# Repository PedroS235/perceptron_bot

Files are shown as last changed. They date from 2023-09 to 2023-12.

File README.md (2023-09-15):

# Perceptron Bot: Your Path to Autonomous Robotics

**Welcome to the Perceptron Bot Repository!**

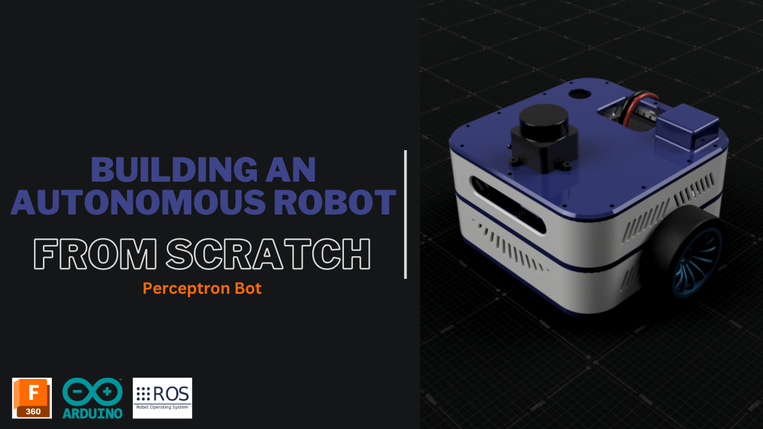
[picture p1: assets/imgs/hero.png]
Perceptron Bot


## Table of contents

<!--toc:start-->

- [Table of contents](#table-of-contents)
- [Introduction](#introduction)
- [Getting Started](#getting-started)
  - [Dependencies](#dependencies)
- [Vision and Purpose](#vision-and-purpose)
- [Repository Highlights](#repository-highlights)
- [YouTube Series](#youtube-series)
- [Join the Adventure](#join-the-adventure)
- [Documentation](#documentation)
- [License](#license)
- [Contact](#contact)
  <!--toc:end-->

## Introduction

Welcome to the captivating world of the Perceptron Bot!
This project embarks on an exhilarating journey, chronicled through an
immersive YouTube series, guiding you through the creation of an autonomous
robot right from its foundational components. The Perceptron Bot, at its core,
serves as the dynamic canvas for this venture, offering a versatile platform
to assemble a range of integral elements, including LiDAR, onboard computing,
and a diverse array of sensors.

## Getting Started

To begin with, you will need to clone this repo. Since it contains submodules,
you will need to clone using the following command:

```sh
git clone --recurse-submodules git@github.com:PedroS235/perceptron_bot.git
```

### Dependencies

- Ubuntu 22.04
- PlatformIO (CLI)
- ROS Humble and above

## Vision and Purpose

The Perceptron Bot isn't just a robot – it's a realization of a vision.
Its purpose is to empower robotic enthusiasts, both beginners and experts alike,
with the tools and knowledge to construct a differential robot capable of autonomous operation.
Designed to be a living example of adaptability, this robotic platform paves
the way for seamless integration of future enhancements and additional sensors.
Its architecture is meticulously crafted to ensure effortless integration,
facilitating the continuous evolution of your robotic creation.

## Repository Highlights

Within this repository, you'll find the core of the Perceptron Bot project:

- **Low-Level Drivers:** Essential low-level drivers are the backbone of the robot's functionality.
- **Setup Scripts:** Curated scripts expedite setup and streamline the integration of the Perceptron Workspace [`perceptron_ws`](https://github.com/PedroS235/perceptron_ws) – a ROS-driven workspace housing critical packages.
- **Documentation:** A set of guidelines and documentation to follow along.

## YouTube Series

The captivating YouTube series offers a holistic learning experience:

- **Design in 3D:** Craft an elegant chassis design through 3D modeling, merging aesthetics and functionality.
- **Delve into Low-Level Development:** Explore motor drivers and serial protocols, unraveling the mysteries of low-level robotics.
- **Simulation with Gazebo:** Immerse yourself in virtual simulation using Gazebo, refining your bot's behavior in diverse scenarios.
- **Master ROS2 and Navigation:** Elevate your coding skills with ROS2, culminating in the integration of the Navigation2 stack for autonomous navigation.

## Join the Adventure

Enthusiasts and developers are invited to contribute to the Perceptron Bot project:

1. **Fork this Repository:** Create a personal development space.
2. **Branch Out:** Develop your contributions in dedicated branches.
3. **Ignite Change:** Tackle issues, enhance features, and propose new ideas.
4. **Submit Pull Requests:** Initiate conversations about your contributions.

## Documentation

- [Bill of Materials (BOM)](./docs/bom.md)
- [CAD & STL](./CAD/README.md)

## License

The Perceptron Bot project is licensed under the `MIT` license, encouraging exploration, modification, and sharing within the global robotic community.

## Contact

Need guidance, insights to share, or eager to collaborate? You can connect with me at `pmbs.123@gmail.com`.
Let's shape the future of autonomous robotics together.

Embark on a transformative journey with the Perceptron Bot—where innovation
meets realization, and where passion ignites automation. Our adventure starts here.

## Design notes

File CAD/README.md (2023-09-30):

# CAD & STL files

<!--toc:start-->

- [CAD Instructions](#cad-instructions)
- [CAD Parameters](#cad-parameters)
- [Printing Instructions](#printing-instructions)
  - [Printing Settings](#printing-settings)
- [External Components CAD Authors](#external-components-cad-authors)
<!--toc:end-->

In this directory, you can find all the CAD files and also ready to print STLs.

## CAD Instructions

There are 3 types of file extensions, `.f3d`, `.f3z` and `.step`. In case you are
working with a CAD software other than **Autodesk Fusion 360**, just use the `.step`
version. Otherwise, use the `.f3d` and `.f3z`. The difference is that `.f3z` contains
all the external components used on the design.

In case you want to build along the second [episode](https://youtu.be/XiTxWWNvyg0) of the series,
you can make use of the **components** folder, which contains all the components CAD
files for you to make use of them.

On the other hand, in case you just want to have the completed robot design,
to adapt some part for instance, you can use the files starting with `perceptron_bot`.

## CAD Parameters

| Name | value (mm) |
| --- | --- |
| **m2_nut** | 4 |
| **m3_nut** | 5.6 |
| **m3_head** | 6.0 |
| **hole_offset** | 0.5 |
| **chassis_size** | 170 |
| **l298_hole** | 38.0 |
| **l298_hole_h** | 36.74 |
| **l298_hole_d** | 3.0 |
| **pc_size_w** | 100 (odroid N2+) \| 56.0 (Pi4)  |
| **pc_size_h** | 91.0 (odroid N2+) \| 85.0 (Pi4) |
| **pc_hole_placement** | 9.75 (odroid N2+) \| 3.5 (Pi4)  |
| **pc_hole_w** | 71.5 (odroid N2+) \| 49.0 (Pi4) |
| **pc_hole_h** | 71.5 (odroid N2+) \| 58.0 (Pi4) |
| **pc_hole_d** | 3.0 (odroid N2+) \| 2.5 (Pi4) |
| **motor_hole_w** | 16.2 |
| **motor_hole_h** | 14.2 |
| **motor_hole_d** | 3.0 |
| **motor_offset** | 13.0 |
| **space_b_plates** | 38.0 |
| **pillars_offset** | 6.0 |

## Printing Instructions

Inside the `STL` folder, you can find all the necessary files that are to be printed.
You should print each file only once.

From all the files, only 2 parts require support material. These are the `wheel_frame` and `top_plate`.

### Printing Settings

- **Filament:** PLA/PETG
- **Infill:** 20%+
- **Perimeters:** 2 or 3
- **Supports**: No supports required execpt the 2 parts mentioned above.

> **Additional note:** For the caster wheel parts, please make sure to orient the parts
> in a **reasonable orientation**. For the rest of the parts, the default orientation is
> the expected.

## External Components CAD Authors

| Component | Link |
| --- | --- |
| Arduino Nano | https://grabcad.com/library/arduino-nano--1 |
| Pin Female Headers  | https://grabcad.com/library/pin-header-female-1 |
| Odroid N2+ | https://grabcad.com/library/odroid-n2-3 |
| Buck Converter | https://grabcad.com/library/dc-dc-4-5-28v-to-0-8-20v-output-3a-mp1584en-step-down-buck-converter-1 |
| PCB Prototype Board | https://grabcad.com/library/pcb-board-prototype-3x7cm-1 |
| L298N Driver | https://grabcad.com/library/l298n-driver-1/details?folder_id=3747362 |
| Raspberry Pi 4 | https://grabcad.com/library/raspberry-pi-4-model-b-1 |
| XT60E Mount | https://grabcad.com/library/xt60e-m-3 |

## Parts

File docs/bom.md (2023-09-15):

# Bill of Materials for Perceptron

<!--toc:start-->

- [Robot Components](#robot-components)
  - [Optional](#optional)
- [Tools](#tools)
- [Hardware](#hardware)
  <!--toc:end-->

## Robot Components

| Component Name | Link |
| --- | --- |
| **Robot Chassis** | [CAD Files](../CAD/README.md) |
| **DC Motor with Encoder** | [Amazon.de](https://www.amazon.de/-/en/gp/product/B07WRYQZNR/ref=ppx_yo_dt_b_asin_title_o06_s01?ie=UTF8&psc=1) |
| **L298N Motor Driver** | [Amazon.de](https://www.amazon.de/-/en/gp/product/B07MY33PC9/ref=ppx_yo_dt_b_asin_title_o06_s01?ie=UTF8&psc=1) |
| **2D LiDAR** | [Amazon.de](https://www.amazon.de/-/en/gp/product/B0B1VD2PJH/ref=ppx_yo_dt_b_asin_title_o06_s01?ie=UTF8&psc=1) |
| **Arduino Nano** | [Amazon.de](https://www.amazon.de/gp/product/B0725CFKWK/ref=ppx_yo_dt_b_asin_title_o09_s00?ie=UTF8&psc=1) |
| **Buck Converter** | [Amazon.de](https://www.amazon.de/-/en/MP1584EN-Downward-Adjustable-Converter-Arduino/dp/B07MY2XP21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) \| [Amazon.de](https://www.amazon.de/-/en/Yizhet-LM2596-Buck-Converter-3-0/dp/B0823P6PW6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) |
| **Onboard PC** | [Raspberri Pi 4 (4Gb)](https://www.amazon.de/-/en/dp/B07TC2BK1X?smid=APDMNWF4LOY5Y&ref_=chk_typ_imgToDp&th=1) \| [Odroid N2+](https://www.hardkernel.com/shop/odroid-n2-with-4gbyte-ram-2/) |
| **4S Lipo Battery 1500mAh** | [Amazon.de](https://www.amazon.de/-/en/Battery-1550mAh-designed-Quadcopters-discharge/dp/B095BVC7M2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) |
| **XT60E-M Mounting Plug** | [Amazon.de](https://www.amazon.de/-/en/Original-XT60E-M-Mounting-Socket-Battery/dp/B08D6375DJ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) |
| **Caster Wheel Bearing** | [Amazon.de](https://www.amazon.de/-/en/Bearing-Groove-Miniature-Rubber-Shielded/dp/B07SS3YRLS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) |
| **Caster Wheel O-Rings** | [Amazon.de](https://www.amazon.de/-/en/Gvolatee-Sealing-Assortment-Sanitary-SodaStream/dp/B0BNQCFG38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) |
| **Rocker Switch** | [Amazon.de](https://www.amazon.de/-/en/gp/product/B09T9CMST1/ref=ppx_yo_dt_b_search_asin_title?ie=UTF8&psc=1) |

### Optional

| Component Name | Link |
| --- | --- |
| **Ultrasonic Sensor** | [Amazon.de](https://www.amazon.de/-/en/AZDelivery-ultrasonic-compatible-rangefinder-Raspberry/dp/B072N473HD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) |
| **Webcam** | [Pi Camera](https://www.amazon.de/-/en/AZDelivery-Camera-Raspberry-Pi-Parent/dp/B01M6UCEM5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) \| Or any webcam |
| **Power Jack Socket** | [Amazon.de](https://www.amazon.de/gp/product/B07TRKJF2G/ref=ppx_yo_dt_b_asin_title_o02_s01?ie=UTF8&psc=1) |

## Tools

| Component Name | Link |
| --- | --- |
| **Soldering Iron** | [Amazon.de](https://www.amazon.de/-/en/Soldering-200-450-Adjustable-Temperature-Tweezers/dp/B09C84DNYL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) |

## Hardware

| Component Name | Link |
| --- | --- |
| **M3 Screws**  | [Amazon.de](https://www.amazon.de/-/en/Assortment-Hexagonal-Cylinder-Threaded-Stainless/dp/B0B3MGZ7T2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) |

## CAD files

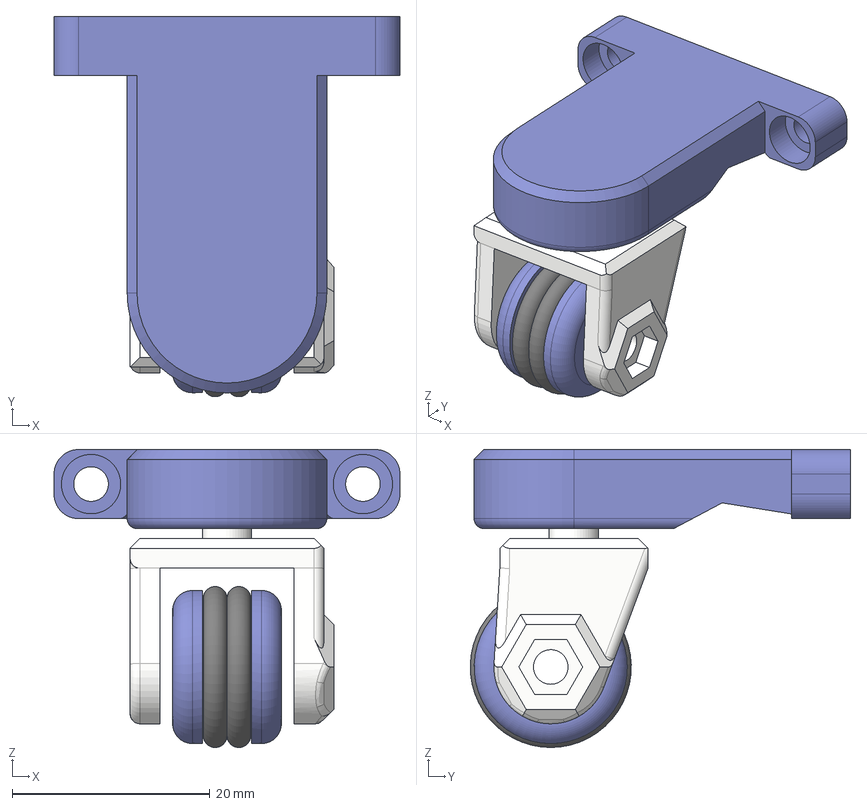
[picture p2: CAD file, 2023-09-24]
CAD/caster wheel.step
35.0 x 38.5 x 30.1 mm
Attatchement
Wheel
Wheel Frame
O ring
O ring(Mirror)
bearing

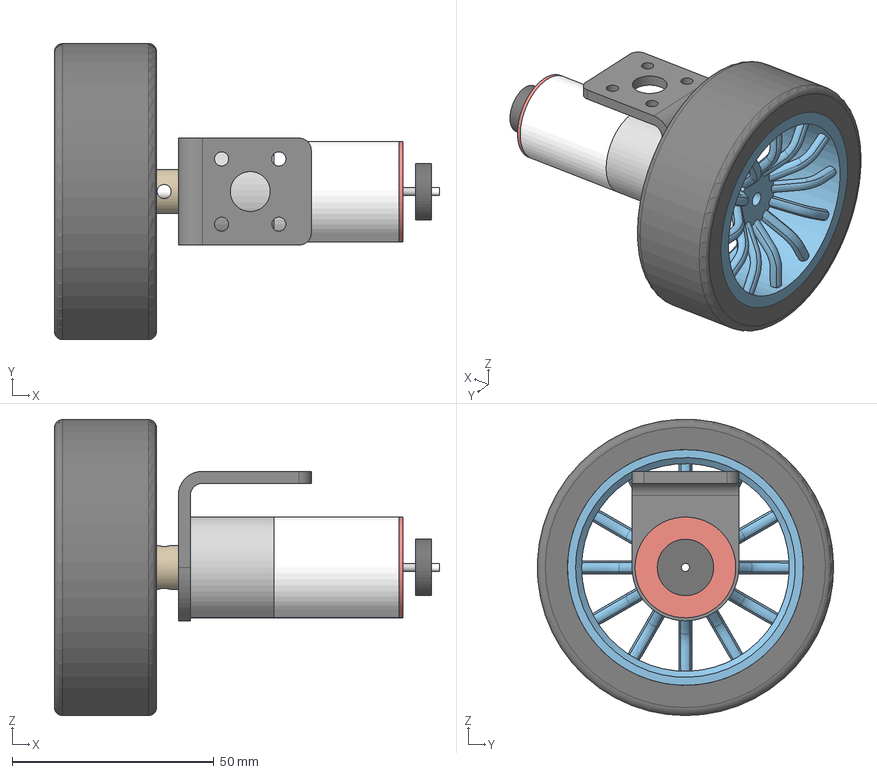
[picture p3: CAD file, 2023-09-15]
CAD/Components/DC Motor.step
95.5 x 73.5 x 73.5 mm
Rim
Tire
Brass connector
Angle bracket
Motor

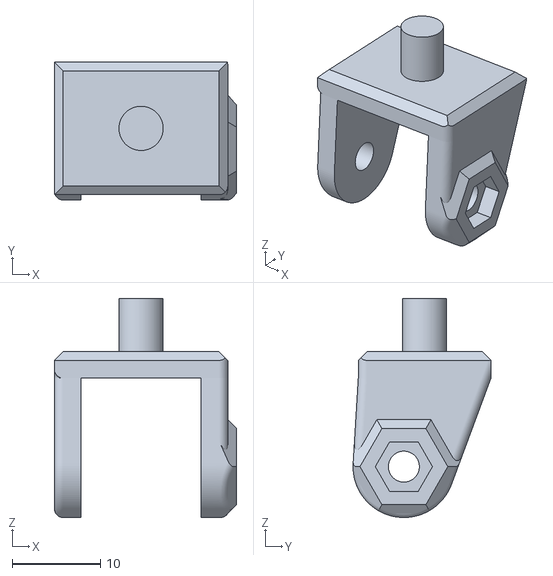
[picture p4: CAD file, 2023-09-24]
CAD/STL/Caster Wheel/Wheel Frame.stl
20.6 x 15.6 x 24.8

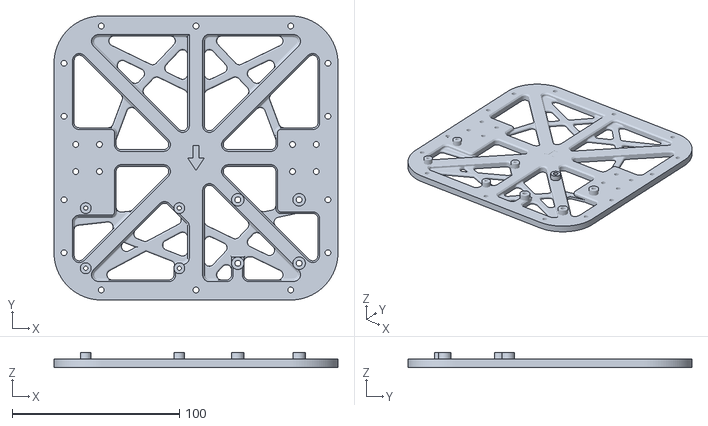
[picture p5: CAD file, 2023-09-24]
CAD/STL/Robot Chassis/Lower Plate.stl
170.0 x 170.0 x 9.00

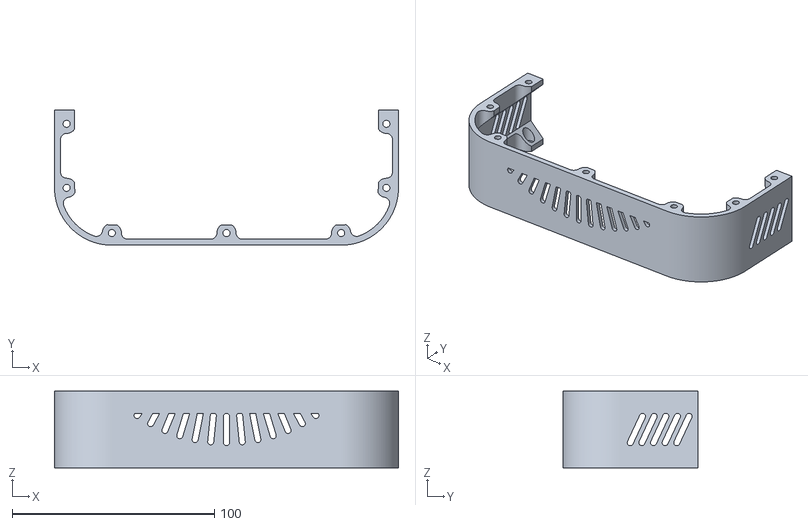
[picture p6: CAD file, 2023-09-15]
CAD/STL/robot_chassis/front_lower_wall.stl
170.0 x 66.9 x 38.0

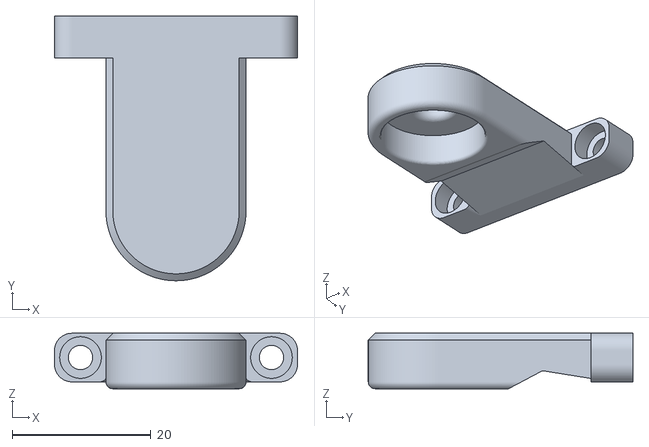
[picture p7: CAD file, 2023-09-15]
CAD/STL/Caster Wheel/Attatchement.stl
35.0 x 38.1 x 8.00

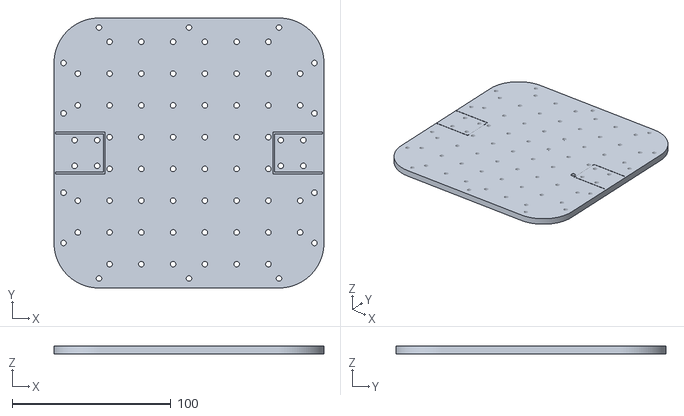
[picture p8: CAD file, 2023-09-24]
CAD/STL/Robot Chassis/Lower Plate Perfurated.stl
170.0 x 170.0 x 5.00

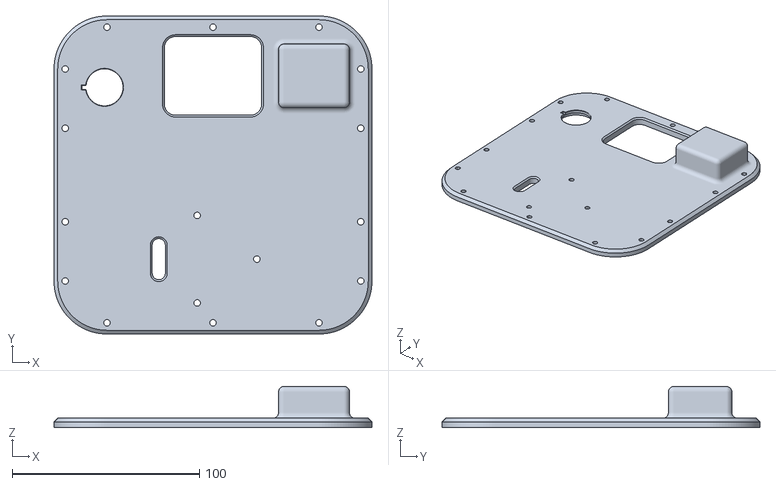
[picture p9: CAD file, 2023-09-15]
CAD/STL/robot_chassis/top_plate.stl
170.0 x 170.0 x 22.0

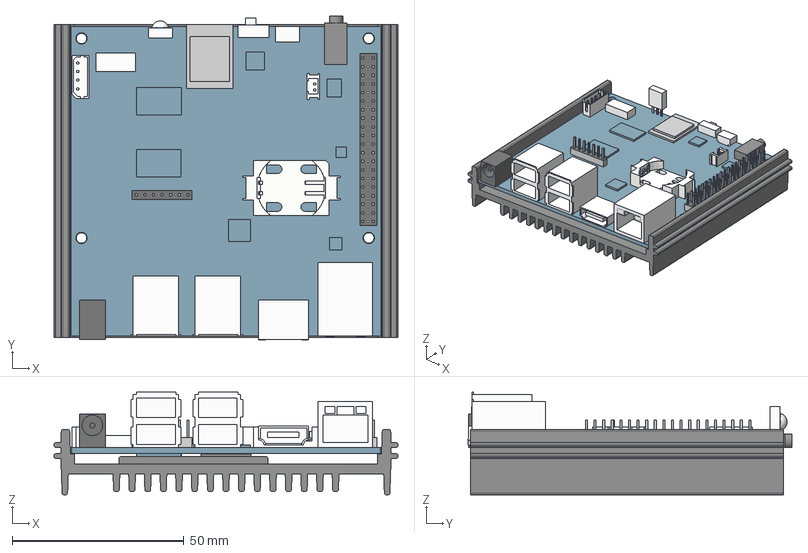
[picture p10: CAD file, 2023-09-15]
CAD/Components/Odroid N2+.step
100.0 x 94.0 x 29.9 mm
Heat Sink
Battery Holder
DC Jack
PCB
HDMI
Ethernet
USB 3.0 B
USB 3.0 A
Audio Jack
Fan Plug
REMOCON
eMMC
MicroUSB
Switch
MicroSD Card Socket
7 Pin Header
UART
40 Pin Header

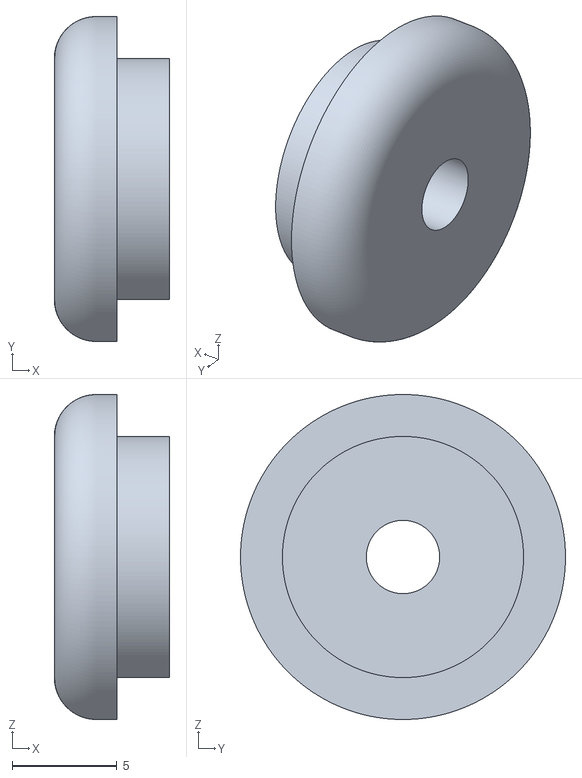
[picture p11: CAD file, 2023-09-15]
CAD/STL/Caster Wheel/Wheel left.stl
5.50 x 15.5 x 15.5

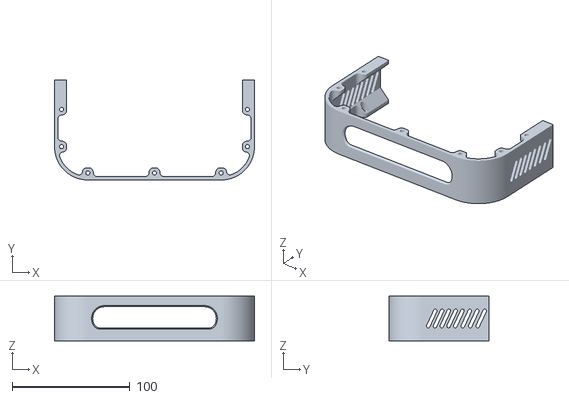
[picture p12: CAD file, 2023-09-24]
CAD/STL/Robot Chassis/Front Upper Wall.stl
170.0 x 85.0 x 38.0

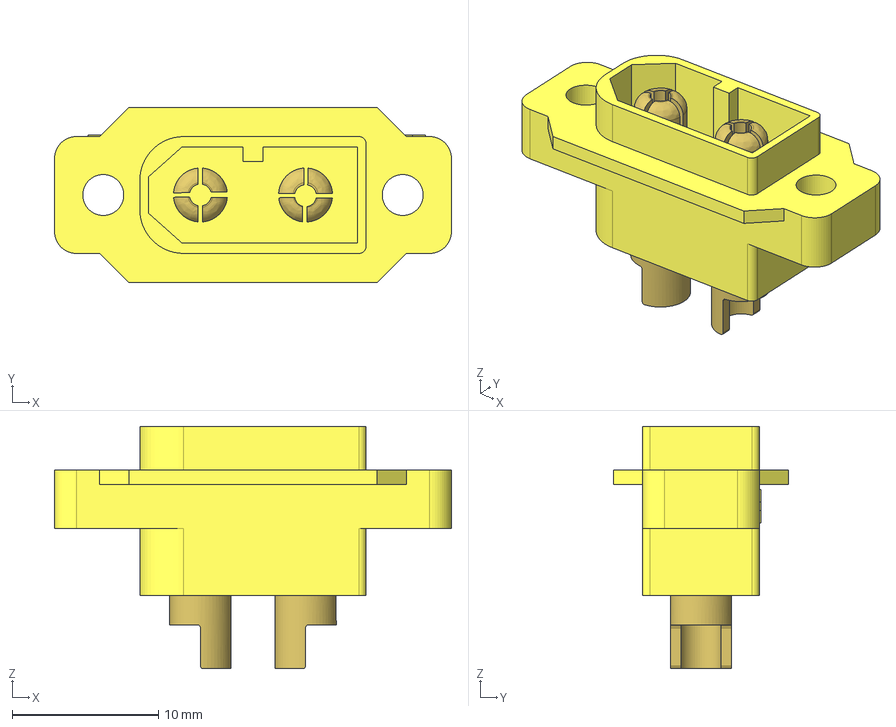
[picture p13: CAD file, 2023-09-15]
CAD/Components/XT60E-M.step
27.2 x 12.0 x 16.6 mm

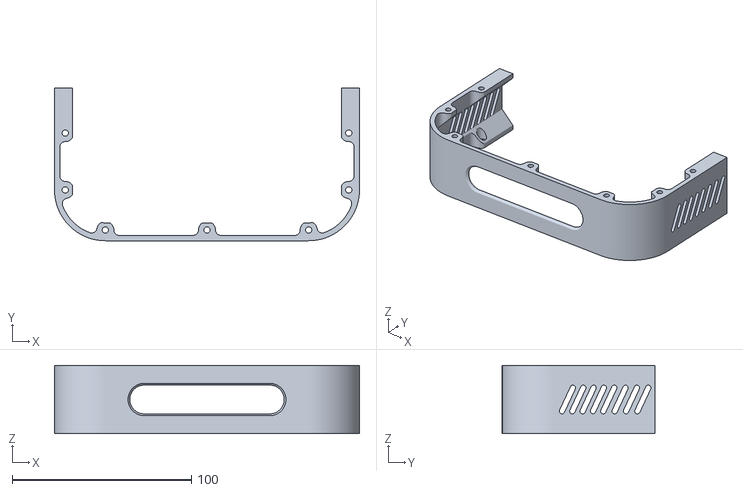
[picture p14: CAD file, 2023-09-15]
CAD/STL/robot_chassis/front_upper_wall.stl
170.0 x 85.0 x 38.0

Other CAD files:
CAD/STL/caster_wheel/wheel_frame.stl
CAD/Components/caster_wheel.step
CAD/STL/robot_chassis/lower_plate.stl
CAD/STL/Caster Wheel/Wheel right.stl
CAD/STL/Robot Chassis/Front Lower Wall Clean.stl
CAD/Components/2D LiDar.step
CAD/Components/4S CNHL LiPO.step
CAD/Components/Buck Converter.step
CAD/Components/caster_wheel_fusion360.f3d
CAD/STL/Robot Chassis/Back Lower Wall.stl
CAD/STL/Robot Chassis/Back Upper Wall.stl
CAD/STL/Robot Chassis/Front Lower Wall USBC&Caster.stl
CAD/STL/Robot Chassis/Middle Plate Odroid.stl
CAD/STL/Robot Chassis/Middle Plate PI.stl
CAD/STL/Robot Chassis/Top Plate.stl
CAD/caster wheel (Fusion360).f3d

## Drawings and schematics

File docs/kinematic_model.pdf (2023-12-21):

## Differential Drive Kinematic Model

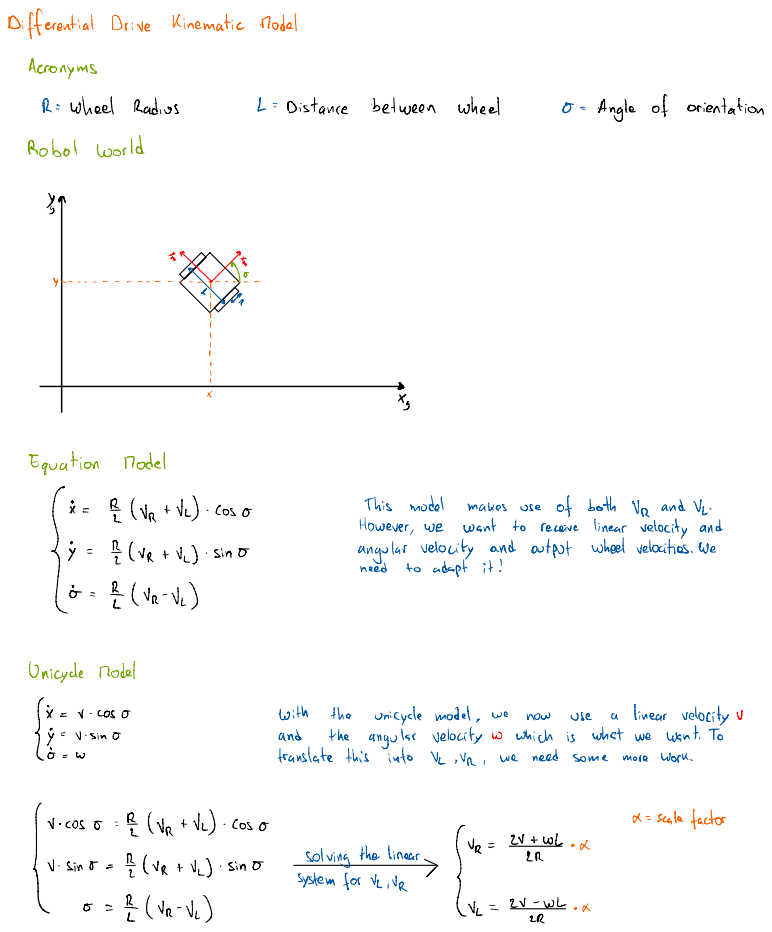
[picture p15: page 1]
Acronyms; Wheel Radios; Distance; between; wheel; Robot world; Equation Model; zos o; This model; makes; use; of both UR and VI; However,; want; receive; linear velocity and; sin o; angular velocity and output wheel velocities.; need; adapt it !; Unicycle Model; COS O; With; the; unicycle model ,; now; linear velocity v; Sin O; and; angular velocity w; which is; what we; want.; translate this; into U ,Vn ,; need some; more; work.; cos o; Scale factor E; the linear; sino=; 2vRw -

Angle of orientation

1) since ye for vim

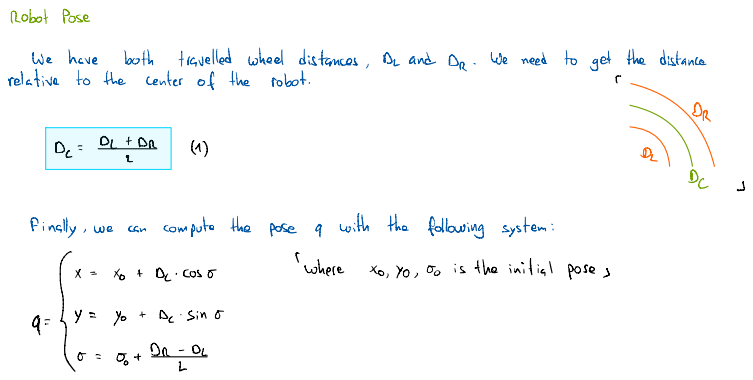
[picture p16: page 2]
Robot Pose; have; both; travelled wheel distances ,; relative to the; center of the; robot.; Finally ,; can; compute the pose; with the following system :; COSO; 'where xo,; is the initial poses E; Sin O

We need to get the distance

De and Dm .

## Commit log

2023-08-31 feat(docs): add a bill of materials page
2023-09-04 chore(motor_ctrl): create empty platformio project w blynk
2023-09-04 feat(docs): add additional necessary components to bom
2023-09-15 chore: add motor controller repo
2023-09-15 chore: remove old motor controller
2023-09-15 chore: add motor controller submodule
2023-09-15 chore(cad): add all cad/stl files
    [2d_lidar.step, 4s_cnhl_lipo.step, XT60E-M.step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]
2023-09-15 docs(main): add a reference to CAD documentation
2023-09-15 docs(cad): add a table with cad parameters
2023-09-15 docs(bom): update the list of components
2023-09-24 chore(cad): add fixed parts
    [2D LiDar.step, 4S CNHL LiPO.step, Attatchement.stl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]
2023-09-30 chore: update motor_controller submodule
2023-12-21 chore: add the kinematic model explanations
2023-12-26 chore: update motor_controller
2023-12-31 chore(motor_controller): update submodule to latest
